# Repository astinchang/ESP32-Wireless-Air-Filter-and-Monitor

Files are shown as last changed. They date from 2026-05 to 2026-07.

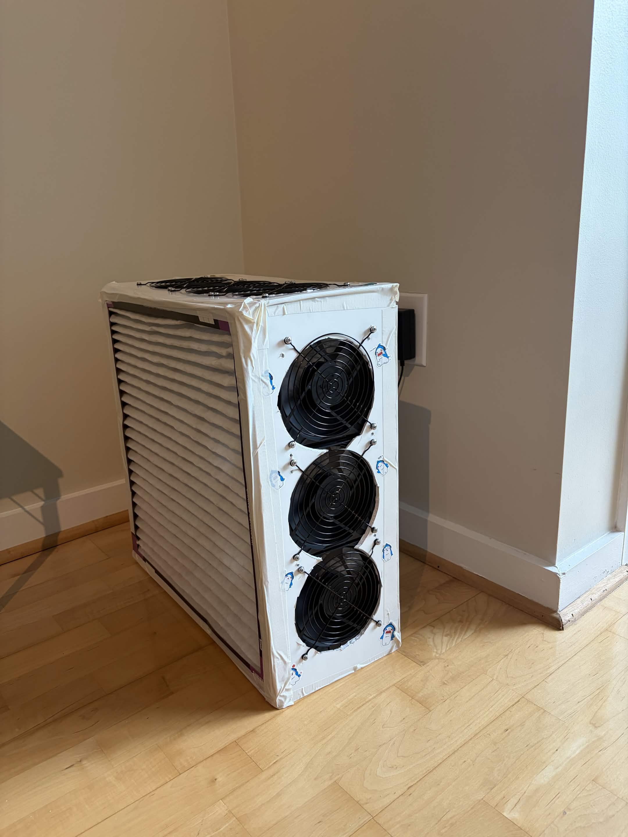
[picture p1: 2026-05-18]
ESP32AirFilterPic.jpg

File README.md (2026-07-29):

# ESP32 Air Filter and Monitor
ESP32AirFilterPic (1)

## **Project Report**

### **Project Overview**

This project is an automatic air filtration system built around an ESP32 microcontroller. The goal of the project is to improve indoor air quality while saving energy by only increasing fan speed when the air quality gets worse. The system uses a particulate matter sensor to measure the amount of particles in the air, a temperature and humidity sensor to monitor environmental conditions, PWM-controlled fans to move air through filters, a MicroSD card module to log air quality data over time, and WiFi tracking so that air quality trends could be monitored from a phone or laptop.

The basic idea is that the ESP32 reads sensor data, decides how dirty the air is, and adjusts the speed of the fans accordingly. If the particulate matter level is low, the fans can run at a lower speed to save power. If the particulate matter level rises, the fans ramp up to clean the air more quickly. This makes the system more efficient than having the fans run constantly. I also included a push button that can interrupt the system to force the fans off, for safety.

### **Components and Their Purpose**

- The main MCU for the project is the ESP32C6-DevKitC-1. It implements the basic features I need to get this project running: I2C, SPI, and UART communication, with WiFi and PWM capabilities. The ESP32 is also low power.
- The PMS5003 particulate matter sensor measures the amount of particulate matter in the air. This component is polled to check air quality at the PM2.5 (particles <2.5um diameter) level, although it does estimate other particle sizes, useful for data reporting. We use this sensor to control the fans' PWM level.
- The HDC3022 temperature and humidity sensor measures the surrounding temperature and humidity. This sensor really helps the node be a more complete source of information, because air quality readings can be affected by humidity. Also useful for more complete, environmental monitoring.
- The PWM PC fans are used to pull air through the filter. They are controlled using PWM output from the ESP32. This is necessary for saving energy and making the air filter respond gradually to different air quality levels.
- The air filters physically remove particles from the air as the fans pull air through the system. These are the part of the project that actually performs the cleaning.
- The MicroSD card module is used for non-volatile data logging. This allows the system to save particulate matter, temperature, and humidity data over time. The MicroSD module is important because it lets the user look back at how air quality changed instead of only seeing the current reading.
- The foam board was used as the physical body of the air filter. It held the fans, filters, sensors, and wiring together. While it worked for a prototype, it was not as sturdy or polished as a real product enclosure.

CREDIT TO JOEY FOX FOR THE AIR FILTER DESIGN: https://itsairborne.com/building-a-pc-fan-corsi-rosenthal-box-68e7cd1ca570 

### **Problems Encountered**

One of the biggest issues was the physical wiring and construction. Since the project was built as a prototype, wiring parts from the wall and connecting everything cleanly was more difficult than expected. The system had several separate parts that needed power, especially with needing to split the 12V power from the wall adapter 3 ways: the 2 sets of fans and buck converter to the breadboard (I split the 6 fans into 2 sets because I didn't feel comfortable daisy chaining 6 together). I also realized midway that using the flimsy breadboard wire was probably not safe and causing overheating, so buying new wire and using wire nuts was necessary, although it made keeping the wiring organized a challenge.

Another issue was that the project was built using a breadboard and foam board instead of a custom PCB and enclosure. This made the system easier to prototype and change, but it also made it more fragile and less clean-looking. Wires were mostly loose, connections were less secure, and the final build was not as sturdy as a real embedded product.

### **Comparison to Real-World Embedded Systems**

This project is similar to real-world embedded systems because it uses sensors, a microcontroller, actuator control, data logging, and low-power design ideas. Like many real embedded systems, it reads information from the environment, processes that data, and controls hardware based on the result. It also uses common embedded communication methods such as serial communication, I2C, SPI, PWM, and WiFi.

The project is different from a real-world embedded system in its physical construction. A commercial air quality monitor or smart air purifier would likely use a mounted PCB, proper connectors, a stronger enclosure, and more fixed wiring. Real products also usually go through more testing for safety, durability, airflow efficiency, and long-term reliability. In comparison, this project was more of a functional prototype built with available class materials, breadboard wiring, and foam board.

### **Future Improvements**

With more time and resources, the biggest improvement would be moving the circuit off the breadboard and onto a custom PCB. This would make the system much more reliable, compact, and easier to mount inside an enclosure. Another improvement would be using 3D printing to create a better electrical box and outer enclosure. A 3D-printed enclosure would protect the electronics, organize the wiring, and make the project look closer to a real consumer product.

Overall, this project successfully implements an ESP32-controlled smart air filter. It senses air quality, adjusts fan speed, and logs environmental data, while also showing how embedded systems can be used to make everyday devices more customizable and energy efficient.

## **Wiring Diagrams**

AirFilterWallPowerDiagram
<br>
The diagram above shows how the system is powered from the wall outlet. As I said before, I separated the PC fans into 2 sets of 3 daisy chained together, because I didn't want to daisy chain all of them together. Starting from the wall outlet, I used an AC to DC plug and barrel jack to two terminal connector to separate the voltage and ground wire. Afterwards, took voltage wire and split it into 3 wires: two for the aforementioned fans, one leading to 12V to 5V buck converter for the ESP32 input voltage. All grounds in this chain are tied to a universal ground inside of a screw terminal bus bar. The breadboard/ESP32 logic is described in the next diagram:
<br>
<br>

AirFilterESP32PinoutDiagram
<br>
Diagram above shows the ESP32 pinout I used to connect all peripherals using the ESP32 and 2 breadboards. As for the power, the 3.3V power was supplied by the ESP32, the 5V power was used as the input for the MCU, and all grounds were tied to the screw terminal bus bar. For the peripherals, pins 4-5 are used for UART to the particle sensor, pin 6 is used for PWM to control the fan speed, pin 0 is used for digital input (input pullup) for the fan shut off button, pins 22-23 are used for I2C to the temp/humidity sensor, and finally pins 18-21 are used for SPI to the microSD card module. 
<br>
<br>

## Libraries Used
The following libraries/APIs were used:

- Arduino.h: Core Arduino/ESP32 functions such as pinMode, delay, millis, Serial, and basic sketch structure.
- Wire.h: Arduino I2C library used to communicate with the HDC3022 temperature/humidity sensor.
- WiFi.h: ESP32 WiFi library used to create the ESP32 access point and host the web dashboard.
- Adafruit_PM25AQI: Adafruit library used to read data from the PMS5003 particulate matter sensor over UART.
- Adafruit_HDC302x: Adafruit library used to read temperature and humidity from the HDC3022 sensor.
- SPI.h: Arduino SPI library used for communication with the microSD card module.
- SD.h: Arduino SD card library used to create and append data to airlog.csv on the microSD card.

## KiCAD Build
*Implemented hardware designed above in dedicated PCB with slight differences (FIRST SOLO BUILD DON'T JUDGE LOL):
- ESP32-C6-WROOM-1 microcontroller
- USB-C programming through CP2102N
- 5 V to 3.3 V regulation
- I2C, SPI, and UART expansion headers
<br>
IF TRYING TO GET THIS TO WORK FROM MY FILES MAKE SURE TO DOWNLOAD THESE LIBRARIES: <br>
- 10171746-00021LF <br>
- ESD122DMYR <br>
- espressifLibraries <br>

<br>

<br>

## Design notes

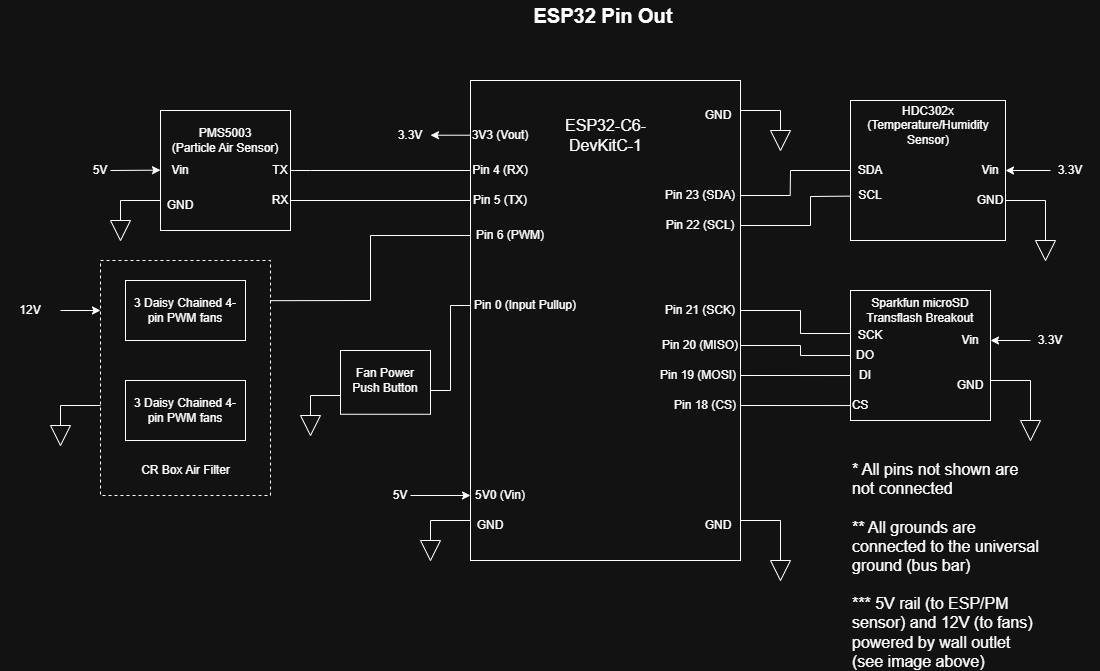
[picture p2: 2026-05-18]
AirFilterESP32PinoutDiagram.png

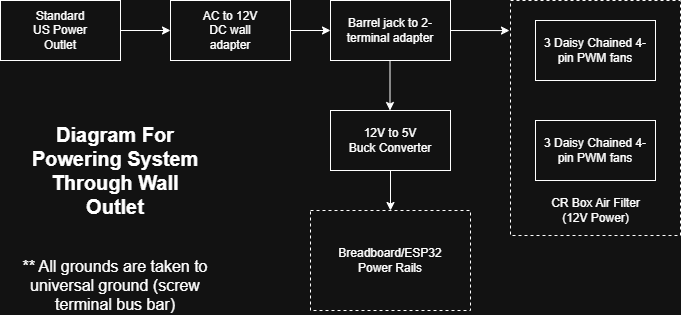
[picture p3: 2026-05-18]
AirFilterWallPowerDiagram.png

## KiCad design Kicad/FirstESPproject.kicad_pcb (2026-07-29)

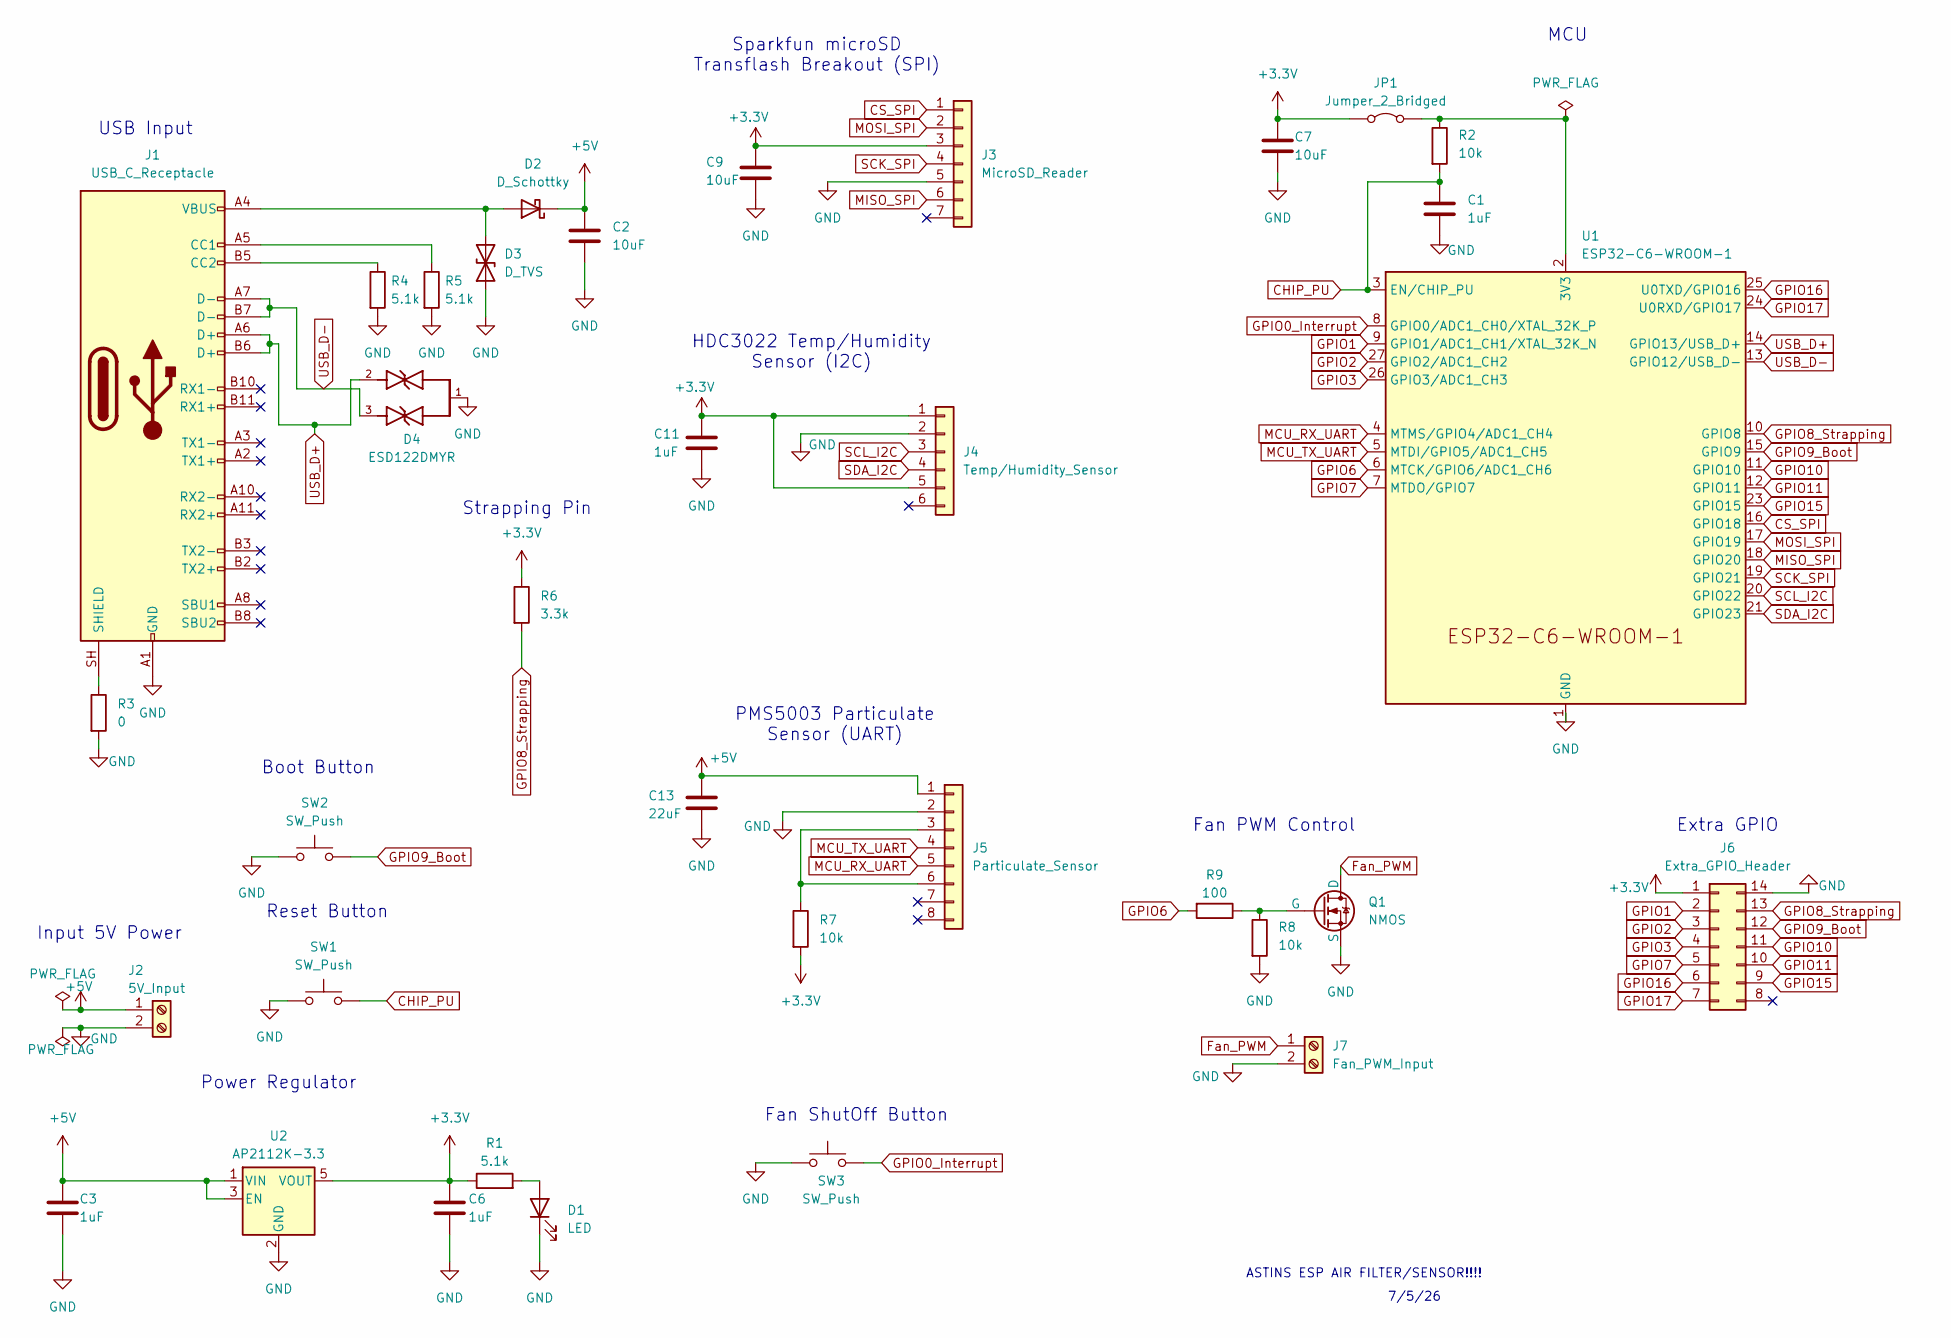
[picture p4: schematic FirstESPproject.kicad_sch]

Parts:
C1, C3, C6, C11: 1uF; C_0603_1608Metric; MFG Part Number CC0603ZRY5V7BB105
C2, C7, C9: 10uF; C_0805_2012Metric; MFG Part Number CC0805KRX5R7BB106
C13: 22uF; C_1206_3216Metric; MFG Part Number CC1206MKX5R8BB226
D1: LED; LED_0603_1608Metric; MFG Part Number 150060RS75000
D2: D_Schottky; D_SOD-123; MFG Part Number 1N4148W-TP
D3: D_TVS; D_SOD-123F; MFG Part Number SMF5-0A
D4: ESD122DMYR; DIO_ESD122DMYR; PARTREV A
J1: USB_C_Receptacle; USB_C_Receptacle_Amphenol_12401610E4-2A; MFG Part Number 12401610E4#2A
J2: 5V_Input; TerminalBlock_MaiXu_MX126-5.0-02P_1x02_P5.00mm; MFG Part Number MX126R-5.0-02P-GN01-Cu-S-A
J3: MicroSD_Reader; PinSocket_1x07_P2.54mm_Vertical; MFG Part Number 929974-01-07-RK
J4: Temp/Humidity_Sensor; PinSocket_1x06_P2.54mm_Vertical; MFG Part Number 61300611821
J5: Particulate_Sensor; PinSocket_1x08_P2.54mm_Vertical; MFG Part Number 61300811821
J6: Extra_GPIO_Header; PinSocket_2x07_P2.54mm_Vertical; MFG Part Number 61301421821
J7: Fan_PWM_Input; TerminalBlock_MaiXu_MX126-5.0-02P_1x02_P5.00mm; MFG Part Number MX126R-5.0-02P-GN01-Cu-S-A
JP1: Jumper_2_Bridged; SolderJumper-2_P1.3mm_Bridged_RoundedPad1.0x1.5mm
Q1: NMOS; SOT-23; MFG Part Number BVSS138LT1G
R1, R4, R5: 5.1k; R_0603_1608Metric; MFG Part Number RC0603FR-075K1L
R2, R7, R8: 10k; R_0603_1608Metric; MFG Part Number RC0603JR-0710KL
R3: 0; R_0603_1608Metric; MFG Part Number RC0603JR-070RL
R6: 3.3k; R_0603_1608Metric; MFG Part Number RC0603FR-073K3L
R9: 100; R_0603_1608Metric; MFG Part Number RMCA0603JT100R-HP
SW1, SW2, SW3: SW_Push; SW_PUSH_6mm; MFG Part Number TL1105AF160Q
U1: ESP32-C6-WROOM-1; MFG Part Number ESP32-C6-WROOM-1-N8
U2: AP2112K-3.3; SOT-23-5; MFG Part Number AP2112K-3.3TRG1

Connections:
+3.3V: C6.1, C7.1, C9.1, C11.1, J3.3, J4.1, J4.5, J6.1, JP1.1 (A), R1.1, R6.1, R7.2, U2.5 (VOUT)
+5V: C2.1, C3.1, C13.1, D2.1 (K), J2.1, J5.1, U2.1 (VIN), U2.3 (EN)
CHIP_PU: C1.1, R2.2, SW1.2, U1.3 (EN/CHIP_PU)
CS_SPI: J3.1, U1.16 (GPIO18)
Fan_PWM: J7.1, Q1.1 (D)
GND: C1.2, C2.2, C3.2, C6.2, C7.2, C9.2, C11.2, C13.2, D1.1 (K), D3.1 (A1), D4.1, J1.A1 (GND), J1.A12 (GND), J1.B1 (GND), J1.B12 (GND), J2.2, J3.5, J4.2, J5.2, J6.14, J7.2, Q1.3 (S), R3.2, R4.2, R5.2, R8.2, SW1.1, SW2.1, SW3.1, U1.1 (GND), U1.28 (GND), U1.29 (GND), U2.2 (GND)
GPIO0_Interrupt: SW3.2, U1.8 (GPIO0/ADC1_CH0/XTAL_32K_P)
GPIO1: J6.2, U1.9 (GPIO1/ADC1_CH1/XTAL_32K_N)
GPIO2: J6.3, U1.27 (GPIO2/ADC1_CH2)
GPIO3: J6.4, U1.26 (GPIO3/ADC1_CH3)
GPIO6: R9.2, U1.6 (MTCK/GPIO6/ADC1_CH6)
GPIO7: J6.5, U1.7 (MTDO/GPIO7)
GPIO8_Strapping: J6.13, R6.2, U1.10 (GPIO8)
GPIO9_Boot: J6.12, SW2.2, U1.15 (GPIO9)
GPIO10: J6.11, U1.11 (GPIO10)
GPIO11: J6.10, U1.12 (GPIO11)
GPIO15: J6.9, U1.23 (GPIO15)
GPIO16: J6.6, U1.25 (U0TXD/GPIO16)
GPIO17: J6.7, U1.24 (U0RXD/GPIO17)
MCU_RX_UART: J5.5, U1.4 (MTMS/GPIO4/ADC1_CH4)
MCU_TX_UART: J5.4, U1.5 (MTDI/GPIO5/ADC1_CH5)
MISO_SPI: J3.6, U1.18 (GPIO20)
MOSI_SPI: J3.2, U1.17 (GPIO19)
unnamed: D1.2 (A), R1.2
unnamed: D2.2 (A), D3.2 (A2), J1.A4 (VBUS), J1.A9 (VBUS), J1.B4 (VBUS), J1.B9 (VBUS)
unnamed: J1.A5 (CC1), R5.1
unnamed: J1.B5 (CC2), R4.1
unnamed: J1.SH (SHIELD), R3.1
unnamed: J5.3, J5.6, R7.1
unnamed: JP1.2 (B), R2.1, U1.2 (3V3)
unnamed: Q1.2 (G), R8.1, R9.1
SCK_SPI: J3.4, U1.19 (GPIO21)
SCL_I2C: J4.3, U1.20 (GPIO22)
SDA_I2C: J4.4, U1.21 (GPIO23)
USB_D+: D4.2, J1.A6 (D+), J1.B6 (D+), U1.14 (GPIO13/USB_D+)
USB_D-: D4.3, J1.A7 (D-), J1.B7 (D-), U1.13 (GPIO12/USB_D-)

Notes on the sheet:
Reset Button
PMS5003 Particulate Sensor (UART)
Power Regulator
Boot Button
USB Input
Input 5V Power
Fan ShutOff Button
Sparkfun microSD Transflash Breakout (SPI)
ASTINS ESP AIR FILTER/SENSOR!!!!
7/5/26
Extra GPIO
MCU
Strapping Pin
HDC3022 Temp/Humidity Sensor (I2C)
Fan PWM Control

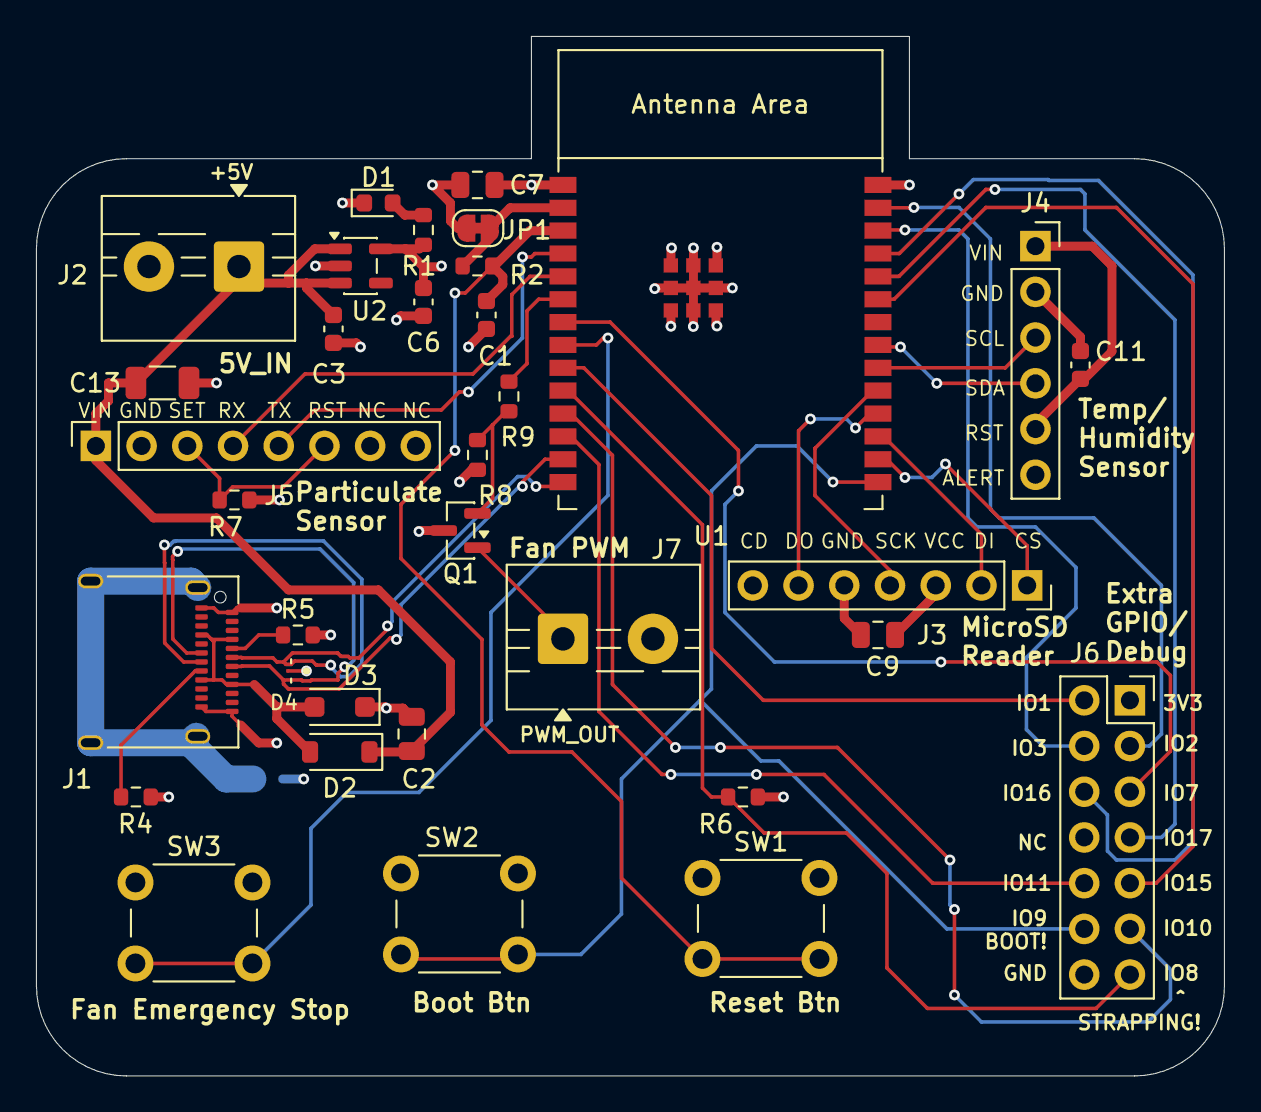
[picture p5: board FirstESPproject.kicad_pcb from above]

Board: 4 copper layers, 66.0 x 57.8 mm, 35 parts (1 on the bottom side), 36 nets.

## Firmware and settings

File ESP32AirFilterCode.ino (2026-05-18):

#include <Arduino.h>
#include <Wire.h>
#include <WiFi.h>
#include "Adafruit_PM25AQI.h"
#include <Adafruit_HDC302x.h>
#include <SPI.h>
#include <SD.h>

// PIN DEFINITIONS
// for I2C temp/humid sensor
#define SDA_PIN 23
#define SCL_PIN 22
// for UART PMS sensor
#define RX_PIN 4  
#define TX_PIN 5 
// for fan PWM
#define FAN_PWM_PIN 6
// for manual override button
#define BTN_PIN 0
// SD card SPI 
#define SD_CS_PIN 18
#define SD_MOSI_PIN 19
#define SD_MISO_PIN 20
#define SD_SCK_PIN 21

// PMS5003 uses 9600 baud
#define PMS_BAUD 9600

// PWM settings for fans
#define PWM_FREQ 25000      // 25 kHz common for 4-wire PWM PC fans
#define PWM_RESOLUTION 8    // duty cycle range: 0-255

// WiFi settings:
const char* ssid = "ESP32-AirFilter";
const char* password = "airfilter123";
WiFiServer server(80);
String header;

IPAddress apIP;
unsigned long lastWiFiPrintTime = 0;
const unsigned long WIFI_PRINT_INTERVAL_MS = 10000;  // print every 10 sec

// define sensors
HardwareSerial pmsSerial(1); // UART1 on ESP32
Adafruit_PM25AQI aqi = Adafruit_PM25AQI();
Adafruit_HDC302x hdc = Adafruit_HDC302x();

// timer variables for serial monitor prints
unsigned long lastPrintTime = 0;
const unsigned long PRINT_INTERVAL_MS = 5000;

// timer variables for button debounce / ISR
volatile bool buttonPressed = false;
volatile unsigned long lastInterruptTime = 0;

bool fanEnabled = true;

bool sdReady = false;
void logDataToSD();
// true  = PM2.5 controls PWM
// false = fan forced off

// hold sensor values
uint16_t latestPM1 = 0;
uint16_t latestPM25 = 0;
uint16_t latestPM10 = 0;

uint16_t latestPM25Env = 0;
uint16_t latestPM10Env = 0;
uint16_t latestAQI = 0;

double latestTempC = 0.0;
double latestHumidity = 0.0;

int latestFanDuty = 0;

// button ISR
void IRAM_ATTR buttonISR() {
  unsigned long currentTime = millis();

  // Simple debounce
  if (currentTime - lastInterruptTime > 250) {
    buttonPressed = true;
    lastInterruptTime = currentTime;
  }
}

// helper functions to setup sensors
void setupPMS5003() {
  Serial.println("Starting PMS5003 UART...");

  pmsSerial.begin(PMS_BAUD, SERIAL_8N1, RX_PIN, TX_PIN);

  // PMS5003 needs boot time before first read
  Serial.println("Waiting 30 seconds for PMS5003 fan/laser to stabilize...");
  delay(30000);

  if (!aqi.begin_UART(&pmsSerial)) {
    Serial.println("ERROR: Could not find PMS5003 / PM2.5 sensor.");
    Serial.println("Check: VCC=5V, GND, PMS TX -> ESP32 RX, baud=9600.");
    while (1) {
      delay(1000);
    }
  }

  Serial.println("PMS5003 found.");
}

void setupHDC3022() {
  Serial.println("Starting HDC3022 I2C...");

  Wire.begin(SDA_PIN, SCL_PIN);

  if (!hdc.begin(0x44, &Wire)) {
    Serial.println("ERROR: Could not find HDC3022.");
    Serial.println("Check: VIN=3.3V, GND, SDA, SCL, I2C address 0x44.");
    while (1) {
      delay(1000);
    }
  }

  Serial.println("HDC3022 found.");
}

void setupFanPWM() {
  Serial.println("Starting PWM fan output...");

  ledcAttach(FAN_PWM_PIN, PWM_FREQ, PWM_RESOLUTION);

  ledcWrite(FAN_PWM_PIN, 0);

  Serial.println("PWM fan output ready.");
}

void setupButtonInterrupt() {
  Serial.println("Starting button interrupt input...");

  pinMode(BTN_PIN, INPUT_PULLUP);

  attachInterrupt(digitalPinToInterrupt(BTN_PIN), buttonISR, FALLING);

  Serial.println("Button interrupt ready.");
}

void setupWiFiServer() {
  Serial.println();
  Serial.println("Setting up ESP32 Wi-Fi Access Point...");

  WiFi.softAP(ssid, password);

  apIP = WiFi.softAPIP();

  Serial.print("Connect to Wi-Fi network: ");
  Serial.println(ssid);

  Serial.print("Password: ");
  Serial.println(password);

  Serial.print("Then open this IP address in a browser: ");
  Serial.println(apIP);

  server.begin();

  Serial.println("Web server started.");
}

void setupSDCard() {
  Serial.println("Starting SD card...");

  SPI.begin(SD_SCK_PIN, SD_MISO_PIN, SD_MOSI_PIN, SD_CS_PIN);

  if (!SD.begin(SD_CS_PIN, SPI)) {
    Serial.println("ERROR: SD card failed or not present.");
    Serial.println("check wiring!");
    sdReady = false;
    return;
  }

  sdReady = true;

  Serial.println("SD card ready.");

  if (!SD.exists("/airlog.csv")) {
    File file = SD.open("/airlog.csv", FILE_WRITE);

    if (file) {
      file.println("time_ms,pm1,pm25,pm10,pm25_env,pm10_env,aqi,temp_c,humidity,fan_enabled,pwm_duty");
      file.close();
      Serial.println("Created airlog.csv with header.");
    } else {
      Serial.println("ERROR: Could not create airlog.csv.");
    }
  } else {
    Serial.println("airlog.csv already exists.");
  }
}

// FAN CONTROL
int getPMDrivenFanDuty(uint16_t pm25) {
  /*
    PM2.5 drives fan PWM.

    Cleaner air  -> lower PWM
    Dirtier air  -> higher PWM
  */

  if (pm25 <= 5) {
    return 0;
  } else if (pm25 <= 12) {
    return map(pm25, 5, 12, 60, 100);
  } else if (pm25 <= 35) {
    return map(pm25, 12, 35, 100, 200);
  } else if (pm25 <= 50) {
    return map(pm25, 35, 50, 200, 255);
  } else {
    return 255;
  }
}

void updateFanPWM() {
  int duty = 0;

  if (fanEnabled) {
    duty = getPMDrivenFanDuty(latestPM25);
  } else {
    duty = 0;
  }

  latestFanDuty = duty;
  ledcWrite(FAN_PWM_PIN, duty);

  Serial.print("[FAN] Enabled: ");
  Serial.print(fanEnabled ? "YES" : "NO");

  Serial.print(" | PM2.5: ");
  Serial.print(latestPM25);
  Serial.print(" ug/m3");

  Serial.print(" | PWM Duty: ");
  Serial.print(duty);
  Serial.println(" / 255");
}

void handleButtonPress() {
  if (buttonPressed) {
    buttonPressed = false;

    fanEnabled = !fanEnabled;

    Serial.println();
    Serial.println("Button interrupt detected!");
    Serial.print("Fan enabled set to: ");
    Serial.println(fanEnabled ? "YES" : "NO");

    updateFanPWM();
  }
}

// read and print helper functions
void readAndPrintSensors() {
  PM25_AQI_Data pmData;

  Serial.println();
  Serial.println("AIR FILTER SENSOR READINGS");
  Serial.println("======================================");

  // Read PMS5003
  if (aqi.read(&pmData)) {
    latestPM1 = pmData.pm10_standard;
    latestPM25 = pmData.pm25_standard;
    latestPM10 = pmData.pm100_standard;

    latestPM25Env = pmData.pm25_env;
    latestPM10Env = pmData.pm100_env;
    latestAQI = pmData.aqi_pm25_us;

    Serial.println("[PMS5003: Particulate Matter]");

    Serial.print("PM1.0 standard: ");
    Serial.print(latestPM1);
    Serial.println(" ug/m3");

    Serial.print("PM2.5 standard: ");
    Serial.print(latestPM25);
    Serial.println(" ug/m3");

    Serial.print("PM10 standard: ");
    Serial.print(latestPM10);
    Serial.println(" ug/m3");

    Serial.print("PM2.5 environmental: ");
    Serial.print(latestPM25Env);
    Serial.println(" ug/m3");

    Serial.print("PM10 environmental: ");
    Serial.print(latestPM10Env);
    Serial.println(" ug/m3");

    Serial.print("PM2.5 AQI US: ");
    Serial.println(latestAQI);
  } else {
    Serial.println("[PMS5003] Could not read PM data this cycle.");
  }

  Serial.println();

  // Read HDC3022
  Serial.println("[HDC3022: Temperature / Humidity]");

  bool hdcOK = hdc.readTemperatureHumidityOnDemand(
    latestTempC,
    latestHumidity,
    TRIGGERMODE_LP0
  );

  if (hdcOK) {
    Serial.print("Temperature: ");
    Serial.print(latestTempC);
    Serial.println(" C");

    Serial.print("Humidity: ");
    Serial.print(latestHumidity);
    Serial.println(" %");
  } else {
    Serial.println("Could not read HDC3022 data this cycle.");
  }

  updateFanPWM();
  logDataToSD();

  Serial.println("================================================");
}

void printWiFiInfoPeriodically() {
  if (millis() - lastWiFiPrintTime >= WIFI_PRINT_INTERVAL_MS) {
    lastWiFiPrintTime = millis();

    Serial.println();
    Serial.println("========== WIFI DASHBOARD INFO ==========");
    Serial.print("Connect to Wi-Fi network: ");
    Serial.println(ssid);
    Serial.print("Password: ");
    Serial.println(password);
    Serial.print("Open browser to: http://");
    Serial.println(apIP);
    Serial.println("=========================================");
  }
}

void logDataToSD() {
  if (!sdReady) {
    Serial.println("[SD] SD card not ready. Skipping log.");
    return;
  }

  File file = SD.open("/airlog.csv", FILE_APPEND);

  if (!file) {
    Serial.println("ERROR: Could not open airlog.csv for appending.");
    return;
  }

  file.print(millis());
  file.print(",");
  file.print(latestPM1);
  file.print(",");
  file.print(latestPM25);
  file.print(",");
  file.print(latestPM10);
  file.print(",");
  file.print(latestPM25Env);
  file.print(",");
  file.print(latestPM10Env);
  file.print(",");
  file.print(latestAQI);
  file.print(",");
  file.print(latestTempC, 2);
  file.print(",");
  file.print(latestHumidity, 2);
  file.print(",");
  file.print(fanEnabled ? 1 : 0);
  file.print(",");
  file.println(latestFanDuty);

  file.close();

  Serial.println("[SD] Logged data to airlog.csv");
}

// WiFi page
void handleWebClient() {
  WiFiClient client = server.available();

  if (client) {
    Serial.println("New web client connected.");

    String currentLine = "";
    header = "";

    while (client.connected()) {
      if (client.available()) {
        char c = client.read();
        header += c;

        if (c == '\n') {
          if (currentLine.length() == 0) {
            // HTTP response header
            client.println("HTTP/1.1 200 OK");
            client.println("Content-type:text/html");
            client.println("Connection: close");
            client.println();

            // HTML page
            client.println("<!DOCTYPE html><html>");
            client.println("<head>");
            client.println("<meta name=\"viewport\" content=\"width=device-width, initial-scale=1\">");
            client.println("<meta http-equiv=\"refresh\" content=\"5\">");
            client.println("<link rel=\"icon\" href=\"data:,\">");

            client.println("<style>");
            client.println("html { font-family: Helvetica; text-align: center; background-color: #f4f4f4; }");
            client.println("body { margin: 0; padding: 20px; }");
            client.println(".card { background-color: white; padding: 20px; margin: 15px auto; border-radius: 12px; max-width: 500px; box-shadow: 0 2px 8px rgba(0,0,0,0.15); }");
            client.println("h1 { color: #222; }");
            client.println("h2 { color: #333; }");
            client.println("p { font-size: 20px; }");
            client.println(".value { font-weight: bold; }");
            client.println("</style>");
            client.println("</head>");

            client.println("<body>");
            client.println("<h1>ESP32 Air Filter Dashboard</h1>");

            client.println("<div class=\"card\">");
            client.println("<h2>What These Values Mean</h2>");
            client.println("<p><strong>PM2.5:</strong> Fine particles in the air that are 2.5 micrometers or smaller. Higher PM2.5 usually means dirtier air.</p>");
            client.println("<p><strong>PM2.5 Environmental:</strong> The sensor-adjusted PM2.5 reading intended to better represent real surrounding air conditions.</p>");
            client.println("<p><strong>AQI:</strong> Air Quality Index. This converts particle pollution into a simpler health-based scale, where lower values mean cleaner air and higher values mean worse air quality.</p>");
            client.println("</div>");

            client.println("<div class=\"card\">");
            client.println("<h2>Particulate Matter</h2>");
            client.println("<p>PM1.0: <span class=\"value\">" + String(latestPM1) + "</span> ug/m3</p>");
            client.println("<p>PM2.5: <span class=\"value\">" + String(latestPM25) + "</span> ug/m3</p>");
            client.println("<p>PM10: <span class=\"value\">" + String(latestPM10) + "</span> ug/m3</p>");
            client.println("<p>PM2.5 Environmental: <span class=\"value\">" + String(latestPM25Env) + "</span> ug/m3</p>");
            client.println("<p>PM10 Environmental: <span class=\"value\">" + String(latestPM10Env) + "</span> ug/m3</p>");
            client.println("<p>PM2.5 AQI US: <span class=\"value\">" + String(latestAQI) + "</span></p>");
            client.println("</div>");

            client.println("<div class=\"card\">");
            client.println("<h2>Temperature / Humidity</h2>");
            client.println("<p>Temperature: <span class=\"value\">" + String(latestTempC, 2) + "</span> C</p>");
            client.println("<p>Humidity: <span class=\"value\">" + String(latestHumidity, 2) + "</span> %</p>");
            client.println("</div>");

            client.println("<div class=\"card\">");
            client.println("<h2>Fan Status</h2>");
            client.println("<p>Fan Enabled: <span class=\"value\">" + String(fanEnabled ? "YES" : "NO") + "</span></p>");
            client.println("<p>PWM Duty: <span class=\"value\">" + String(latestFanDuty) + "</span> / 255</p>");
            client.println("</div>");

            client.println("<p>Page auto-refreshes every 5 seconds.</p>");
            client.println("</body></html>");

            client.println();

            break;
          } else {
            currentLine = "";
          }
        } else if (c != '\r') {
          currentLine += c;
        }
      }
    }

    header = "";
    client.stop();

    Serial.println("Web client disconnected.");
    Serial.println();
  }
}

void setup() {
  Serial.begin(115200);
  delay(1000);

  Serial.println();
  Serial.println("ESP32 Air Filter Sensor + Interrupt PWM + WiFi Dashboard");

  setupHDC3022();
  setupPMS5003();
  setupFanPWM();
  setupButtonInterrupt();
  setupWiFiServer();
  setupSDCard();

  Serial.println("Setup complete. Reading sensors, controlling fans, making webpage...");
}

void loop() {
  handleButtonPress();
  handleWebClient();
  printWiFiInfoPeriodically();

  if (millis() - lastPrintTime >= PRINT_INTERVAL_MS) {
    lastPrintTime = millis();
    readAndPrintSensors();
  }
}

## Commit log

2026-05-18 Rename ESP32AirFilterCode (1).ino to ESP32AirFilterCode.ino
2026-05-18 Rename ESP32AirFilterPic (1).jpg to ESP32AirFilterPic.jpg
2026-07-04 Update README.md
    added credit for espressif kicad library used for implementing project on PCB
2026-07-29 Update README.md
    added readme kicad info
2026-07-29 Add files via upload
    added main kicad files
    [FirstESPproject.kicad_pcb, FirstESPproject.kicad_sch]
2026-07-29 Delete FirstESPproject.kicad_pcb
    moved file to kicad folder
    [FirstESPproject.kicad_pcb]
2026-07-29 Delete FirstESPproject.kicad_pro
    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
2026-07-29 Delete FirstESPproject.kicad_sch
    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
    [FirstESPproject.kicad_sch]
2026-07-29 Update README.md
    added kicad libs
2026-07-29 Add files via upload
    added gerbers
    [FirstESPproject-B_Cu.gbr, FirstESPproject-B_Mask.gbr, FirstESPproject-B_Paste.gbr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]
